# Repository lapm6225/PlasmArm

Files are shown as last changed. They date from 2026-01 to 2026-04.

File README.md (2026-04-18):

# PlasmArm

A 3-DOF (X, Y, Z) SCARA robotic arm controlled by an ESP32 with real-time WebSocket interface. Designed for compact plasma cutting applications in small workshops.

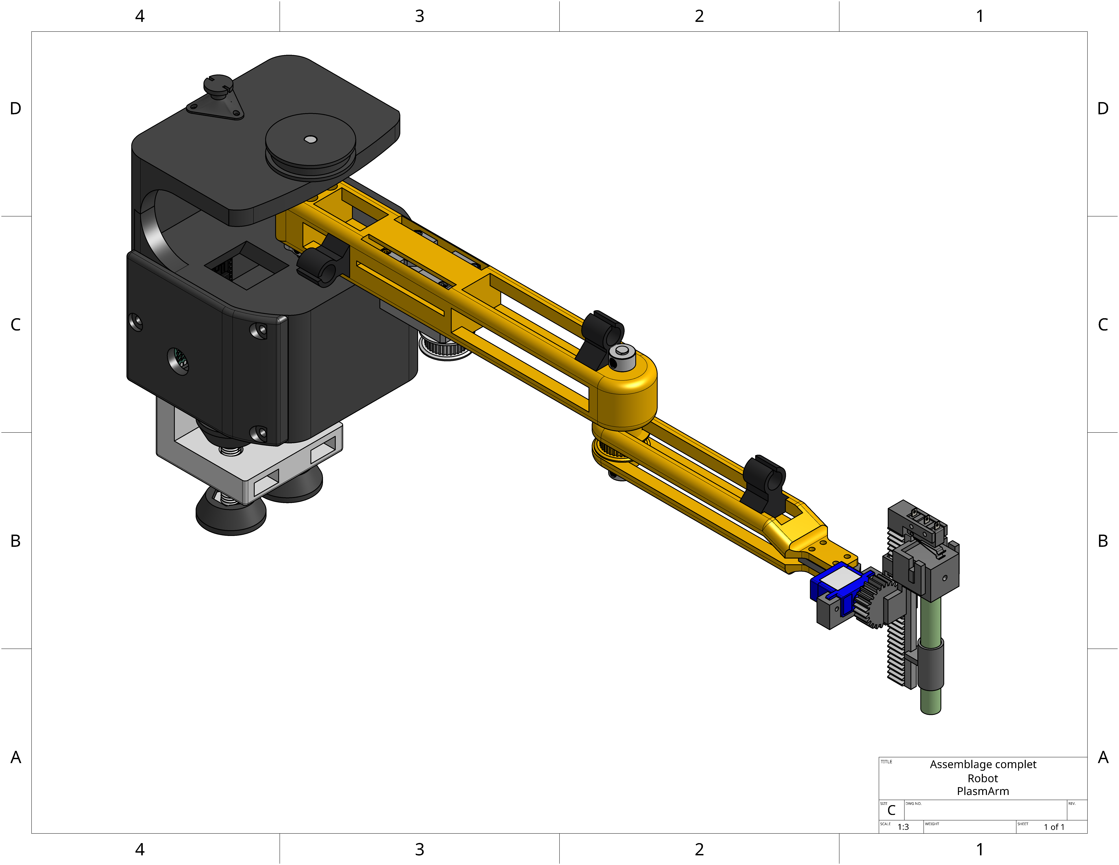
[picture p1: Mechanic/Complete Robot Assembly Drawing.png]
PlasmArm Robot


## Table of Contents

- [Overview](#overview)
- [Project Context](#project-context)
- [Electrical](#Electrical)
  - [Electrical Components](#Electrical-Components)
  - [Bill of Materials](#Bill-of-Materials)
  - [Wiring Diagram](#Wiring-Diagram)
- [Mechanical](#Mechanical)
  - [BoM & Drawings](#BoM-and-Drawings)
  - [Mechanical Project Files](#Mechanical-Project-Files)
  - [Assembly Instructions](#Assembly-Instructions)
- [Software](#Software)
  - [Software Installation](#software-installation)
    - [Prerequisites](#prerequisites)
    - [PlatformIO Setup](#platformio-setup)
    - [Python Client Setup](#python-client-setup)
  - [Configuration](#configuration)
  - [Building and Uploading](#building-and-uploading)
  - [Running the Robot](#running-the-robot)
  - [Architecture Overview](#architecture-overview)
    - [System Modules](#system-modules)
    - [FreeRTOS Task Structure](#freertos-task-structure)
    - [Kinematics](#kinematics)
    - [Trajectory Planning](#trajectory-planning)
  - [Web Interface](#web-interface)
  - [Testing](#testing)
  - [Licenses](#licenses)
  - [Troubleshooting](#troubleshooting)
  - [Project Structure](#project-structure)

---

## Overview

PlasmArm is a proof-of-concept for a compact, table-mounted SCARA robot designed for plasma cutting in small workshops. The robot folds when inactive to save floor space.

### Key Features

- **3-DOF Architecture**: X, Y positioning (2 joints) + Z axis (tool actuation)
- **ESP32** microcontroller with FreeRTOS for real-time dual-core task scheduling
- **Dynamixel XM430** servomotors for shoulder and elbow joints
- **SG90 servo** with rack-and-pinion mechanism for Z-axis
- **Limit switch** for tool contact detection
- **WebSocket** interface for real-time control via web browser
- **DXF import** support for vector drawings
- **PyQt6** graphical user interface

### Current Status

This is a **proof-of-concept** version at reduced scale where the plasma torch and metal sheet are replaced by a pencil and paper for safe testing and validation.

---

## Project Context

### Motivation

PlasmArm emerged from the need for space-saving solutions in small machining workshops. Traditional CNC plasma tables require significant floor space. This project proposes a compact alternative - a table-mounted SCARA robot that folds when inactive to free up workspace.

### Development Method

Agile methodology with incremental feature delivery throughout the project.

---

## Electrical

### Electrical Components

- **ESP32** (esp32doit-devkit-v1 or compatible)
- USB cable for programming

### Motors & Actuators

| Motor | Model | Function |
|---|---|---|
| Shoulder | Dynamixel XM430-W350 | Base joint (X-Y positioning) |
| Elbow | Dynamixel XM430-W350 | Second joint (X-Y positioning) |
| Z-Axis | SG90 (TowerPro) | Tool up/down actuation |
| End Effector | - | Pencil/pen holder (proof of concept) |

### Power Supply

- **12V DC** power supply (90W, 7.5A)
- 12V to 5V buck converter for ESP32 and SG90

### Electronics

- Level shifter (5V to 3.3V)
- Custom PCB (fit in the base)
- Limit switch (normally open) for Z-axis contact detection
- 10kΩ pull-up resistor for limit switch
- Diode (1N4148 or similar) for half-duplex UART

---

### Bill of Materials

| Component | Quantity | Notes |
|---|---|---|
| ESP32 Dev Kit | 1 | esp32doit-devkit-v1 |
| Dynamixel XM430-W350 | 2 | Shoulder and elbow joints |
| SG90 Servo | 1 | Z-axis actuation |
| 12V Power Supply | 1 | 90W, 7.5A |
| Buck Converter | 1 | 12V to 5V |
| Level Shifter | 1 | 5V to 3.3V |
| Limit Switch (NO) | 1 | Z-axis contact detection |
| 10kΩ Resistor | 1 | Pull-up for limit switch |
| 1N4148 Diode | 1 | Half-duplex UART |
| Electrolytic Capacitor | 1 | 10uF |
| Ceramic Capacitor | 3 | 10nF |

### ESP32 Pin Connections

| Function | GPIO Pin | Notes |
|---|---|---|
| Dynamixel RX | 16 | Serial2 RX |
| Dynamixel TX | 17 | Serial2 TX (with diode for half-duplex) |
| SG90 Servo (Z-axis) | 26 | PWM output |
| Limit Switch | 32 | Input with 10kΩ pull-up |
| 5V Power | - | From buck converter |
| 3.3V Reference | - | From Level Shifter |

### Wiring Diagram

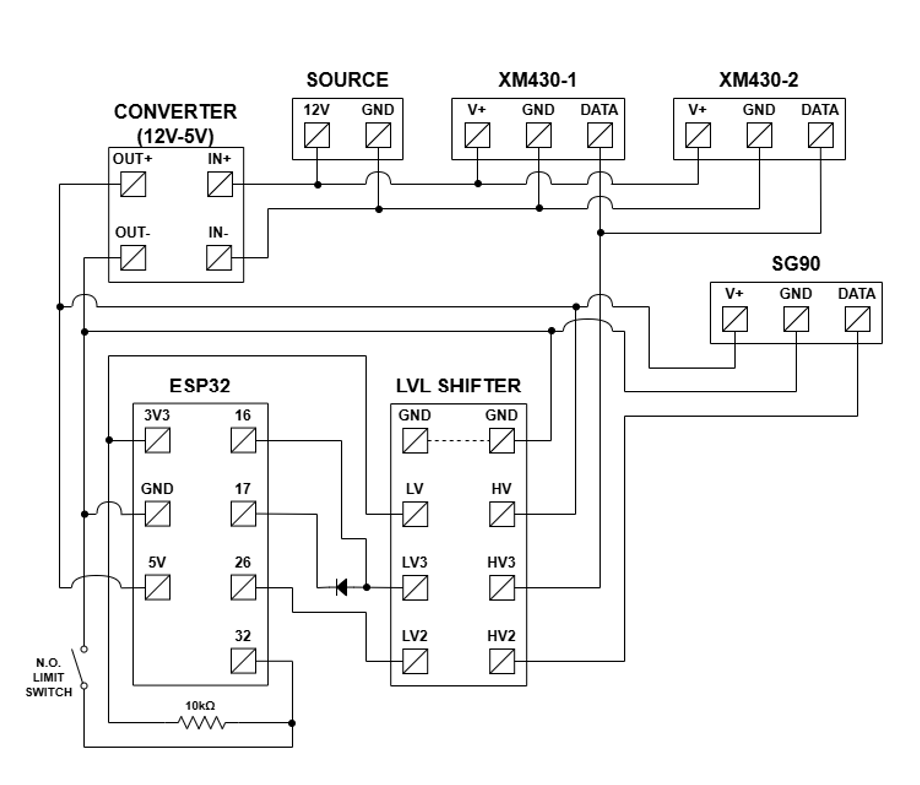
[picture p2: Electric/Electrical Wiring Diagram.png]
Wiring


---

### Connection Details

1. **Dynamixel Motors**: Daisy-chained, communicate via UART through level shifter to ESP32 pins 16 (RX) and 17 (TX)
2. **SG90**: PWM signal from GPIO 26 through level shifter
3. **Limit Switch**: GPIO 32 with 10kΩ pull-up to 3.3V
4. **Half-Duplex**: Diode on GPIO 17 prevents TX from blocking Dynamixel responses

---

### Mechanical 

### BoM and Drawings
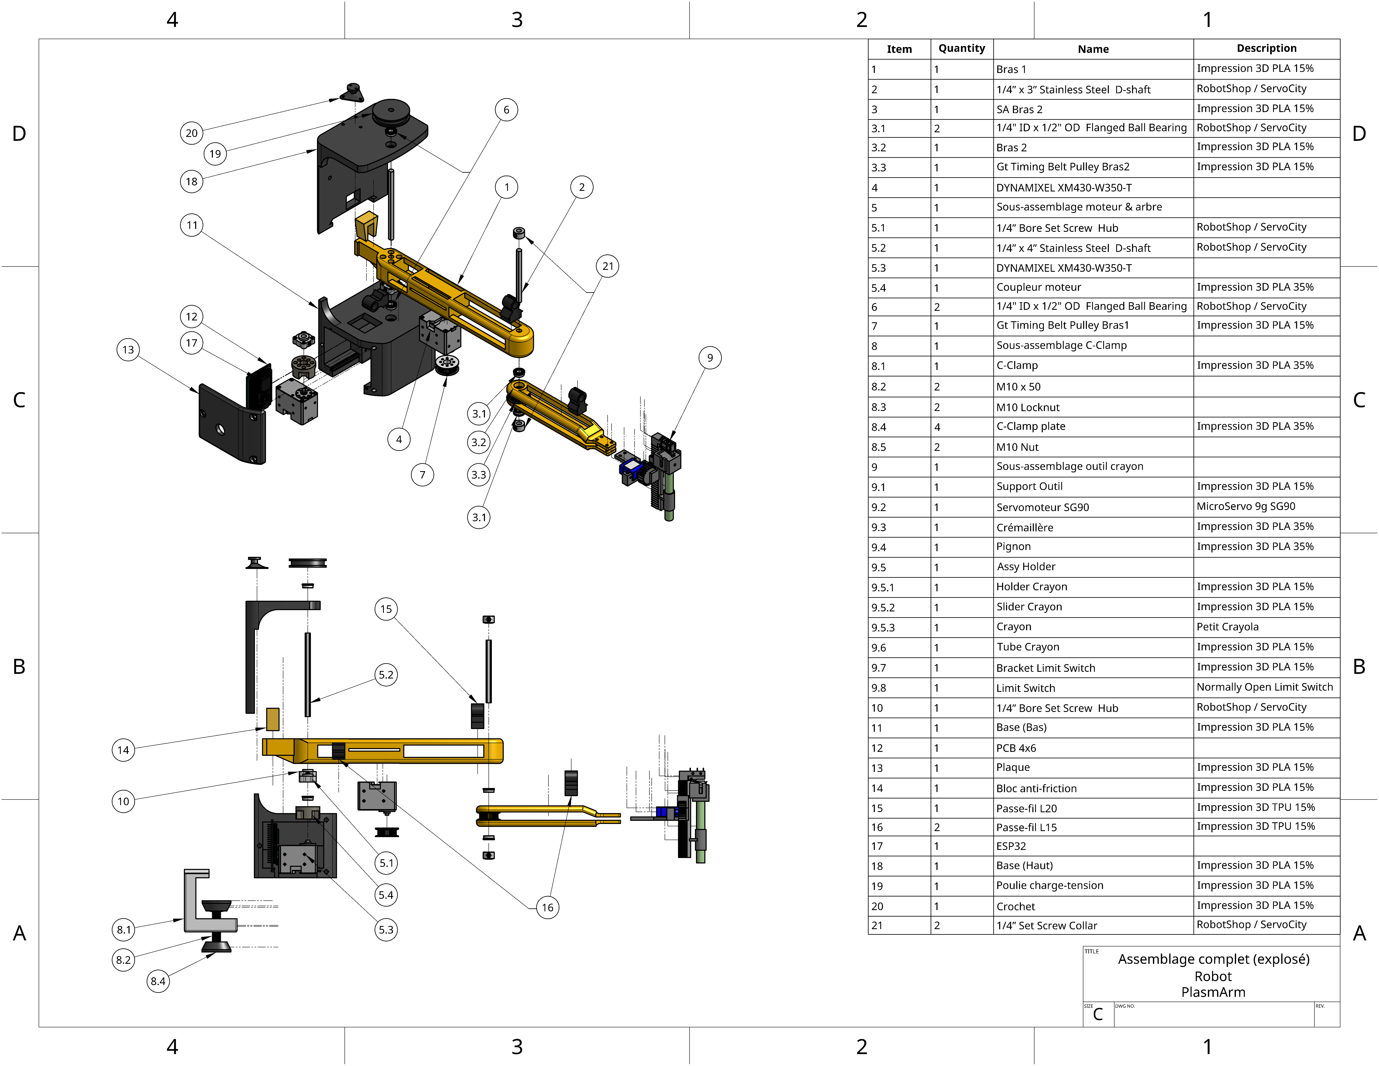
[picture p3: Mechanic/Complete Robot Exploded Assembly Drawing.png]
PlasmArm Robot Exploded

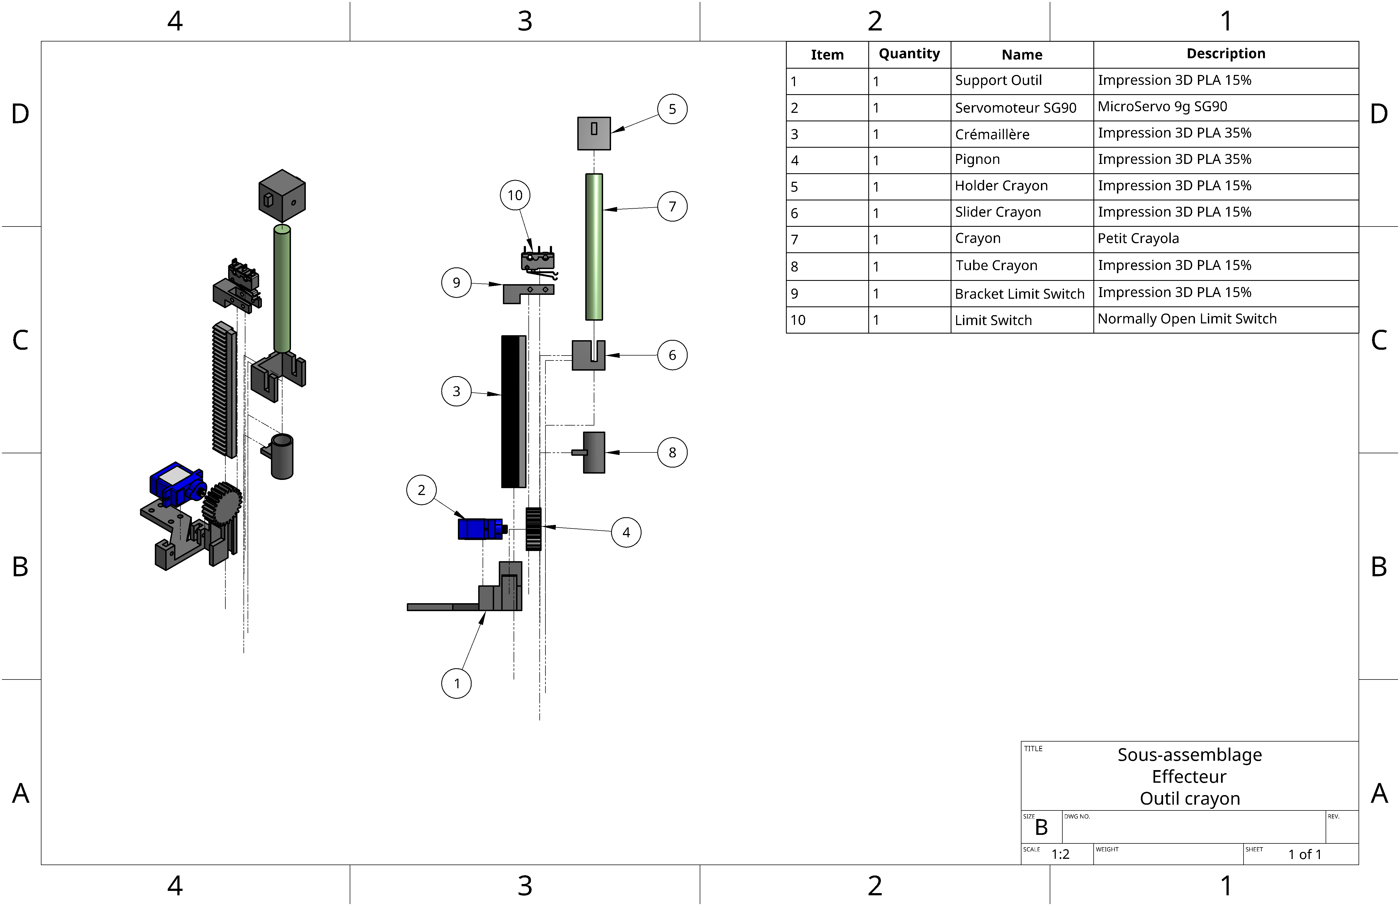
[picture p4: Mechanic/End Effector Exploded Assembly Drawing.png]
End Effector Exploded


### Mechanical Project Files
- [STL Printing Files](Mechanic/STL%20Printing%20Files)
- [STEP Part Files](Mechanic/STEP%20Part%20Files)

### Assembly Instructions
- [Assembly Instructions](Mechanic/Assembly%20Instructions.md)

---
## Software

### Software Installation

### Prerequisites

#### Windows

1. **Python 3.8+** - Download from https://www.python.org/
2. **Git** - Download from https://git-scm.com/
3. **PlatformIO** - Install via pip:
   ```bash
   pip install platformio
   ```

#### Linux/macOS

```bash
# Install Python if not present
brew install python3  # macOS
sudo apt install python3 python3-pip  # Linux

# Install PlatformIO
pip3 install platformio
```

### PlatformIO Setup

1. Navigate to the ESP32 directory:
   ```bash
   cd PlasmArm/ESP32
   ```

2. Install dependencies:
   ```bash
   pio pkg install
   ```

### Python Client Setup

The Python client provides a GUI for importing DXF files and sending commands to the robot.

1. Navigate to the Python directory:
   ```bash
   cd PlasmArm/Python
   ```

2. Create a virtual environment (recommended):
   ```bash
   python -m venv venv
   ```

3. Activate the virtual environment:
   - Windows: `venv\Scripts\activate`
   - Linux/macOS: `source venv/bin/activate`

4. Install dependencies:
   ```bash
   pip install -r requirements.txt
   ```
   
   Required packages:
   - PyQt6 (GUI)
   - websocket-client
   - ezdxf (DXF parsing)

---

## Configuration

### WiFi Configuration

Edit `ESP32/src/Config.h`:

```cpp
// Access Point Mode (create your own network)
#define WIFI_AP_MODE true
#define WIFI_AP_SSID "PlasmArm_ESP32"
#define WIFI_AP_PASSWORD "12345678"

// OR Station Mode (connect to existing WiFi)
#define WIFI_AP_MODE false
#define WIFI_STA_SSID "Your_Network_Name"
#define WIFI_STA_PASSWORD "Your_Password"
```

### Robot Physical Parameters

```cpp
// Arm lengths in millimeters
#define ARM_LENGTH_1 220.05f  // First link (base to elbow)
#define ARM_LENGTH_2 217.65f  // Second link (elbow to end effector)

// Joint angle limits (degrees)
#define THETA1_MIN 0.0f
#define THETA1_MAX 180.0f
#define THETA2_MIN -150.0f
#define THETA2_MAX 150.0f
```

### Motor IDs (Dynamixel)

Default IDs (verify with Dynamixel Wizard):
- Shoulder: ID 1
- Elbow: ID 2

---

## Building and Uploading

### Build the Project

```bash
cd PlasmArm/ESP32
pio run
```

### Upload to ESP32

```bash
pio run -t upload
```

### Open Serial Monitor

```bash
pio device monitor
```

Serial monitor is at **115200 baud**.

---

## Running the Robot

### 1. Power On

Connect the 12V power supply and USB cable to the ESP32.

### 2. Connect to WiFi

If using AP mode:
- Connect to network `PlasmArm_ESP32`
- Password: `12345678`

If using Station mode:
- Robot will connect to your specified WiFi network
- Check serial monitor for IP address

### 3. Send Commands

Use the Python GUI to:
- Move the arm to specific coordinates (jog control)
- Import and draw DXF files
- Control the tool/end effector (pen up/down)

---

## Architecture Overview

### System Modules

The system is divided into three interconnected modules: a PC user interface, an ESP32 embedded control unit and the SCARA arm mechanical unit.

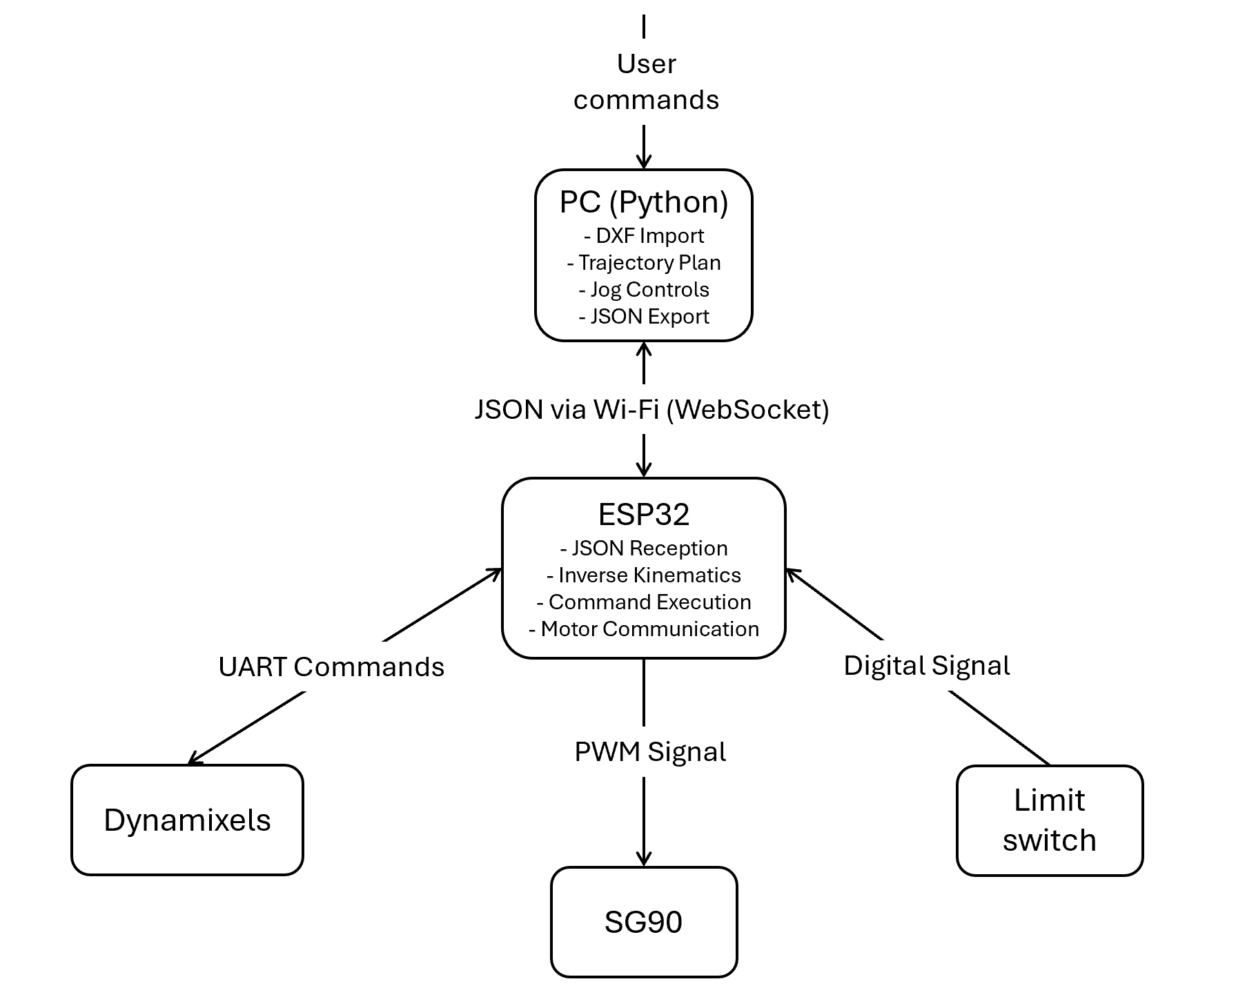
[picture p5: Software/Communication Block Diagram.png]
Communication Block Diagram


#### Module 1: User Interface (PC)

- **Technology**: Python with PyQt6
- **Functions**:
  - Import and parse DXF vector drawings
  - Generate trajectories centered on robot workspace
  - Manual jog controls
  - Export commands as JSON via Wi-Fi

#### Module 2: Embedded Control (ESP32)

- **Technology**: C++ with FreeRTOS
- **Functions**:
  - Receive JSON commands via WebSocket/Wi-Fi
  - Execute inverse kinematics calculations
  - Convert Cartesian coordinates to joint angles
  - High-frequency UART communication with Dynamixel motors

#### Module 3: SCARA Arm (Mechanical)

- **Technology**: 3D printed + Dynamixel servos
- **Components**:
  - Dynamixel XM430-W350 (Shoulder) - Time-Based Profile interpolation
  - Dynamixel XM430-W350 (Elbow) - Time-Based Profile interpolation
  - SG90 with rack-and-pinion for Z-axis
  - Limit switch for tool contact detection

### FreeRTOS Task Structure

The system uses two CPU cores:

```
Core 0: WebHandler (prio 1) + Trajectory Planner (prio 2)
Core 1: Motion Control (prio 3, 100 Hz loop)
```

| Task | Core | Priority | Function |
|---|---|---|---|
| WebHandler | 0 | 1 | Handle WebSocket commands from PC |
| Planner | 0 | 2 | Generate trajectory points from JSON |
| MotionControl | 1 | 3 | Execute motion at 100 Hz |

### Communication Flow

```
Web Client <--WebSocket--> WebHandler <--Command Queue--> Planner
                                                       |
                                                       v
                                            Trajectory Points
                                                       |
                                                       v
                                              Motion Queue
                                                       |
                                                       v
                                              MotionControl --> Motors
```

### Kinematics

The robot uses SCARA inverse kinematics:

#### Forward Kinematics
Convert joint angles (θ1, θ2) to Cartesian (x, y):
```
x = L1*cos(θ1) + L2*cos(θ1+θ2)
y = L1*sin(θ1) + L2*sin(θ1+θ2)
```

#### Inverse Kinematics
Convert Cartesian (x, y) to joint angles (θ1, θ2):
```
Using law of cosines and atan2
```

### Trajectory Planning

1. Receive target position and tool state from JSON
2. Generate linear path with waypoints
3. Apply trapezoidal velocity profile for smooth motion
4. Interpolate at 100 Hz for execution

---

## PyQt Interface Walktrough
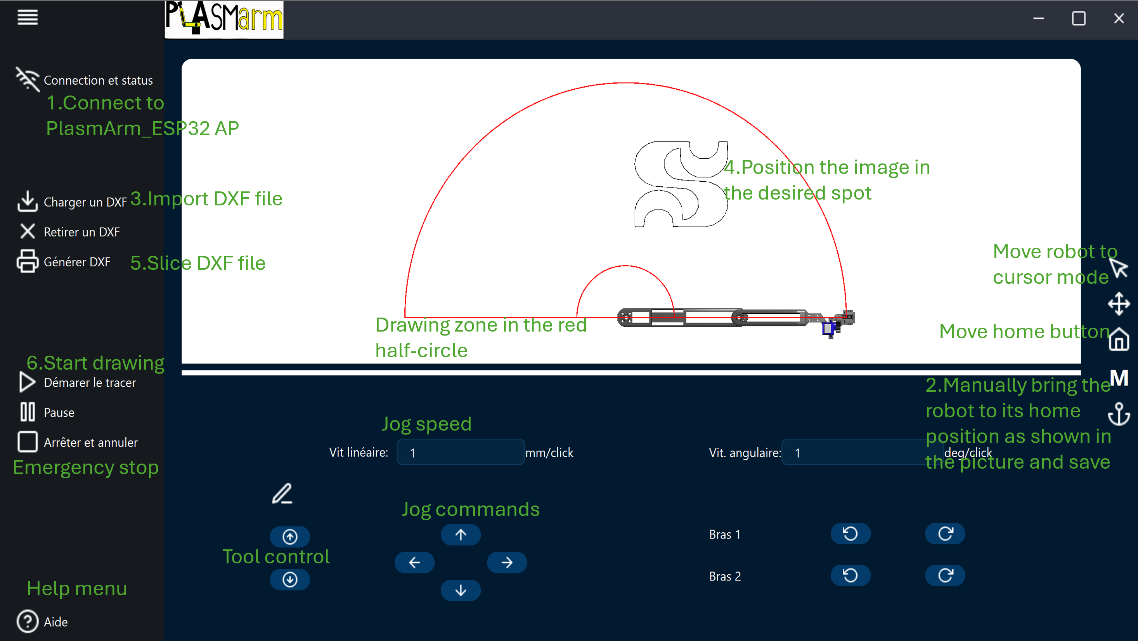
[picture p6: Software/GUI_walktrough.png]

The interface provides:

- **Manual Control**: Move arm to X, Y coordinates
- **DXF Upload**: Send drawing files to robot (via Python client)
- **Status Display**: Show current position and state
- **Tool Control**: Pen up/down commands

### WebSocket Commands

```json
// Move to position
{"type": "MOVE_TO", "x": 200, "y": 200, "speed": 100}

// Delay 
{"type": "DELAY", "ms": 500}

// Tool control
{"type": "TOOL", "state": "DOWN"}
{"type": "TOOL", "state": "UP"}

// Set home position
{"type": "SET_HOME"}
{"type": "SAVE_HOME"}
```

---

## Testing

The project includes built-in tests. Enable them in `ESP32/src/Config.h`:

```cpp
#define RUN_UNIT_TESTS true        // Automated kinematics/planner tests
#define RUN_VISUAL_TESTS true      // Detailed interpolation output
#define RUN_INTERACTIVE_TEST true  // Real hardware serial test
```

### Running Tests

1. Set test flags in `Config.h`
2. Build and upload: `pio run -t upload`
3. Open serial monitor at 115200 baud

See [ESP32/TEST_README.md](ESP32/TEST_README.md) for detailed testing instructions.

---

## Licenses

### Software

The Python code (DXF interpreter, GUI) and C++ firmware (ESP32) are distributed under the **GNU General Public License v3.0**.

This choice is primarily driven by the use of PyQt6, whose strong Copyleft license requires any project integrating it to adopt equivalent distribution conditions. GPLv3 ensures that future improvements by the community remain free and accessible to all.

### Hardware

3D printed models, CAD plans, and electrical schematics are distributed under the **CERN Open Hardware Licence - Weak (CERN-OHL-W)**.

---

## Troubleshooting

### Motors Not Moving

- Check power supply (12V, 3A minimum)
- Verify Dynamixel IDs are correct (default: 1 and 2)
- Check UART wiring (GPIO 16, 17)
- Use Dynamixel Wizard to verify motor communication

### Web Interface Not Loading

- Verify WiFi connection
- Check serial monitor for IP address

### Robot Not Reaching Target

- Check arm length parameters in Config.h
- Verify joint angle limits
- Ensure workspace boundaries are respected (half-circle, y > 0)

### Limit Switch Not Triggering

- Check wiring to GPIO 32
- Verify 10kΩ pull-up resistor is connected
- Test with multimeter

---

## Project Structure

```
PlasmArm/
├── ESP32/
│   ├── src/
│   │   ├── main.cpp           # Entry point, task creation
│   │   ├── Config.h           # All configuration constants
│   │   ├── core/
│   │   │   ├── Kinematics.cpp # Forward/Inverse kinematics
│   │   │   └── Planner.cpp    # Trajectory interpolation
│   │   ├── hardware/
│   │   │   ├── SG90.cpp       # Z-axis servo driver
│   │   │   └── Dynamixel2Arduino # Servo communication
│   │   ├── web/
│   │   │   └── WebServer.cpp  # WebSocket handler
│   │   └── test/              # Unit tests
│   ├── platformio.ini         # PlatformIO config
│   └── AGENTS.md              # Development notes
│
├── Python/
│   ├── main.py                # GUI application (PyQt6)
│   ├── communication.py       # WebSocket client
│   ├── animation.py          # Ui display
│   ├── dxf_display.py       # DXF file  management for ui
│   ├── dxf_parser.py         # DXF file parsing
│   ├── help_dialog.py       # Help window
│   └── requirements.txt      # Python dependencies
│
├── STL/                       # 3D print files (to be added)
│
├── Rapport final.pdf          # Technical report
│
├── LICENSE                    # GPLv3 (software)
│
├── CERN-OHL-W.txt            # Hardware license
│
└── README.md                  # This file
```

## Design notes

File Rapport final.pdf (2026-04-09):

i

UNIVERSITÉ DE SHERBROOKE
Faculté de génie
Département de génie robotique

## RAPPORT DE CONCEPTION FINAL – PLASMARM

Conception agile et ouverte en robotique GRO400

Présenté à
Catherine Véronneau
Raphaël Bisson

Présenté par
Équipe numéro 8
Arnaud Séguin – SEGA0300
Étienne Bérubé – BERE3507
Étienne Landry – LANE2209
Louis Lamontagne – LAML4835 Maxim Laplante – LAPM6225

Sherbrooke - 19 avril 2026

ii

## TABLE DES MATIÈRES

Liste des figures | iii
Liste des tableaux | iii
1. | Description de la réalisation technique du projet | 1
1.1 | Mise en contexte | 1
1.1.1 Objectifs, motivations et impacts visés par le projet | 1
1.1.2 Cahier des charges | 2
1.1.3 Mode de distribution sous licence ouverte, et justification du choix en fonction de l’impact
visé pour le projet | 4
1.2 | Description du système | 5
1.2.1 Architecture globale, modules, etc. | 5
1.2.2 Documentation technique mécanique | 6
1.2.3 Documentation technique informatique | 6
1.2.4 Documentation technique électrique | 6
1.3 | Performances du système et de l’intégration des modules, analysées en lien avec les
objectifs/cahier des charges à rencontrer | 8
1.3.1 Méthodes de validation et tests | 8
1.3.2 Résultats | 10
1.3.3 Recommandations pour la poursuite du projet | 10
1.4 | Bilan des livraisons | 10
2. | Références | 11
Annexe A | Exemple d’annexe | 12
Annexe B | Exemple d’annexe | 13

iii

## LISTE DES FIGURES

Figure 1 : Schéma-bloc de l’architecture globale du PlasmArm | 6
Figure 2 : Schéma électrique des composantes utilisées | 7

## LISTE DES TABLEAUX

Tableau 1 : Spécifications d'ingénierie (critères quantifiables) | 2
Tableau 2 : Fonctions (critères non quantifiables) | 3

1

## 1. DESCRIPTION DE LA RÉALISATION TECHNIQUE DU

## PROJET

### 1.1 MISE EN CONTEXTE

### 1.1.1 OBJECTIFS, MOTIVATIONS ET IMPACTS VISÉS PAR LE PROJET

L'idée du projet PlasmArm a émergé lors d’une discussion avec une connaissance possédant un

atelier d'usinage. Ces échanges ont mis en lumière le fait que les tables de découpe au plasma

CNC traditionnelles monopolisent une surface au sol énorme, ce qui s'avère problématique pour

les petits ateliers. Pour y remédier, le projet propose une alternative compacte : un robot

d'architecture SCARA, fixé au mur ou au sol, qui se replie sur lui-même lorsqu'il est inactif afin de

libérer l'espace de travail. Compte tenu des contraintes de temps, l'équipe réalise une preuve de

concept à échelle réduite où la torche et la tôle sont remplacées respectivement par un crayon et

du papier. Cette approche permet de tester et valider la cinématique, le contrôle et la précision

en toute sécurité, sans les risques et coûts liés au plasma.

Les objectifs de ce mandat sont à la fois matériels et logiciels. Tout d’abord, il s'agit de fabriquer

un bras rigide à trois axes, couvrant le plan XY avec deux joints et utilisant un actionneur pour

déplacer l'outil en Z. Le quatrième axe typique des SCARA, soit la rotation du poignet, a été

volontairement omise, la découpe au plasma étant omnidirectionnelle. Par la suite, sur le plan

informatique, l'objectif est de développer une interface utilisateur en Python et C/C++ intégrant

la cinématique inverse et capable d'interpréter un dessin de type DXF importé par l’utilisateur.

Encore, au niveau électrique, il est primordial de choisir des composantes pertinentes pour la

logique voulue et suffisamment fiables afin d’assurer la communication entre chacune d’entre

elles. Le développement est mené selon la méthode Agile afin de livrer des fonctionnalités de

manière incrémentale tout au long de la progression du projet.

Finalement, la principale motivation de cette démarche s'inscrit dans la philosophie du matériel

et du logiciel libres (Open Source). En diffusant publiquement les plans mécaniques, le code

source et la documentation sur un dépôt GitHub public, l'impact visé est double : optimiser

concrètement l'espace physique dans les petits ateliers industriels et offrir une solution de

2

fabrication automatisée abordable, accessible et reproductible pour l'ensemble de la

communauté maker.

### 1.1.2 CAHIER DES CHARGES

Cette section présente le cahier des charges final du projet PlasmArm, structuré afin de distinguer

les spécifications de performance mesurables des fonctions de conception non quantifiables. Le

tableau suivant regroupe les spécifications techniques pouvant être validées par des mesures

précises ou des données logicielles.

Tableau 1 : Spécifications d'ingénierie (critères quantifiables)

Spécification | Définition | Mesure | Niveau | Flexibilité
Vitesse linéaire | Vitesse de l'effecteur lors du tracé d'un segment. | Calcul logiciel | 0,1 m/s | Min.

Fréquence de
contrôle

Intervalle de rafraîchissement des commandes envoyées par l'ESP32 aux moteurs.

Chronomètre
interne (µs)
20 ms | Max.

Précision
positionnelle

Écart maximal entre la
trajectoire théorique du fichier DXF et le tracé physique.

Mesure
physique

± 1 mm Max.

Rayon de
travail

Distance maximale atteignable entre la base et l'extrémité de l'effecteur.

Mesure sur
CAO

300
mm

Min.

Masse de
l'effecteur

Masse totale de l'assemblage de l'effecteur (SG90, crémaillère, support et crayon).

Mesure sur
CAO
100 g | Max.

Alimentation
électrique

Tension électrique continue requise pour le fonctionnement des servomoteurs Dynamixel.

Multimètre 12 V (DC)

± 0.5 V

Capacité de
charge

Facteur de sécurité sur le couple pouvant être supporté par les servomoteurs Dynamixel.

Calcul
analytique
3 | Min.

Vibrations à
l’effecteur

Mouvements vibratoires dus au backlash des servomoteurs.

Mesure
physique
5 mm | Max.

3

Pour les fonctions dont la réussite dépend de choix architecturaux ou qualitatifs, le tableau

suivant détaille les solutions implémentées lors de l'intégration finale.

Tableau 2 : Fonctions (critères non quantifiables)

Fonctions | Notes à la conception | Respecté?
Être repliable dans l’espace de travail | Utilisation d'une architecture SCARA compacte et repliable permettant une fixation murale ou au sol pour libérer la surface de travail. | Oui

Être stable
mécaniquement

Intégration d'un appui de stabilisation pour assurer le contrebalancement du bras en porte-à-faux et d’un système de tension afin de réduire les vibrations à l’effecteur.

Oui

Piloter les actionneurs Pilotage direct des servomoteurs Dynamixel par l'ESP32 via une communication UART (half-duplex) afin d'éliminer la latence et le bruit observés sur les architectures multi-contrôleurs.

Oui

Détecter le plan de
découpe

Actionnement de la descente du crayon via un servomoteur SG90 et une crémaillère, dont l'arrêt est commandé par un interrupteur de fin de course (limit switch) dès le contact avec le plan.

Oui

Transmettre les
trajectoires

Transmission sans fil des trajectoires de découpe entre l'interface utilisateur PC et le robot par l'envoi de fichiers de commandes au format JSON via Wi-Fi.

Oui

Interpréter des fichiers
DXF

Interface logicielle développée en PyQt6 capable de traiter des fichiers DXF et de les centrer automatiquement par rapport à l'origine du robot.

Oui

Être distribué librement Publication exhaustive du projet sur un dépôt GitHub public, incluant les modèles CAO, le code source, le plan électrique et autres schémas pertinents. Oui

Être abordable | L'utilisation de composants standards et de l'impression 3D permet de respecter un budget réduit.
Oui
Être rigide | Choix d’un taux de remplissage du PLA des bras limitant la
mécaniquement | déformation verticale de l’effecteur due à la gravité et empêchant
l’abimement de l’insertion en D transmettant le mouvement.

Oui

Être compact | Passage des fils afin de limiter leur longueur, branchement des
structurellement | composantes sur un PCB caché et minimisation de la largeur des
pièces mécaniques.

Non

Être facilement | Assemblage et désassemblage simples à comprendre, nécessitant
démontable | peu d’effort physique et modulaires.

Oui

4

Dans le (Tableau 2), le seul critère non-quantifiable n’ayant pas été respecté est l’aspect structurel

compact du robot. Le CAO avait été conceptualisé pour intégrer le proto-board dans la base, mais

l’équipe a rencontré des difficultés au niveau du microcontrôleur ESP32 (pièce défectueuse), et

s’est résignée à utiliser un breadboard à l’extérieur de la base puisque l’équipe ne voulait pas tout

dé-souder et il ne restait pas assez de temps pour faire un PCB.

### 1.1.3 MODE DE DISTRIBUTION SOUS LICENCE OUVERTE, ET JUSTIFICATION DU

CHOIX EN FONCTION DE L’IMPACT VISÉ POUR LE PROJET

Le projet PlasmArm est distribué sous des licences ouvertes afin de permettre la communauté

maker de contribuer à cette technologie de découpe automatisée pour les petits ateliers

d'usinage. Le mode de distribution se divise en deux volets distincts : le logiciel et le matériel.

Pour le volet logiciel, le code source Python, incluant le module d'interprétation des fichiers DXF

et l'interface utilisateur, ainsi que le micrologiciel (firmware) en C++ exécuté par l'ESP32 sont

distribués sous la licence GNU GPLv3. Ce choix est d'abord dicté par l'utilisation de la bibliothèque

PyQt6, dont la licence Copyleft forte impose que tout projet l'intégrant adopte des conditions de

distribution équivalentes. La GPLv3 garantit que les futures améliorations apportées par la

communauté au logiciel de contrôle resteront libres et accessibles à tous.

Pour le volet matériel, les modèles d'impression 3D, les plans CAO et les schémas électriques sont

distribués sous la licence CERN-OHL-W (Open Hardware Licence - Weak). Cette licence est

spécifiquement conçue pour le matériel physique. La version « Weak » assure que toute

modification apportée directement à la conception mécanique du bras SCARA devra être partagée

publiquement. Simultanément, elle permet à un intégrateur d'utiliser ce bras robotique au sein

d'un système industriel plus vaste sans être contraint d'ouvrir les plans de son infrastructure

entière.

En conclusion, ces choix de licences maximisent l'impact visé en assurant que l'innovation au cœur

du PlasmArm demeure un bien commun, favorisant la collaboration technologique tout en

protégeant l'accessibilité de la solution.

5

### 1.2 DESCRIPTION DU SYSTÈME

1.2.1 ARCHITECTURE GLOBALE, MODULES, ETC.

L’architecture du système PlasmArm est conçue de manière modulaire afin d'assurer une

intégration fluide entre le logiciel de contrôle et la mécanique. Le système se divise en trois grands

modules interdépendants : l'interface utilisateur (PC), l'unité de contrôle embarquée (ESP32) et

le bras électromécanique (SCARA).

1. Module Interface Utilisateur et Planification (PC) Le flux d'opération débute sur un ordinateur

hôte via une interface graphique développée en Python (PyQt6). Ce module agit comme le

cerveau directeur. Il est responsable d'importer les dessins vectoriels (.DXF) et de les traduire en

une série de trajectoires centrées sur l'espace de travail du robot. L'interface offre également à

l'utilisateur des contrôles manuels (jog) et le démarrage de la séquence. Une fois la planification

terminée, les commandes de déplacement (coordonnées cartésiennes et états de l'outil) sont

encodées dans un fichier JSON et transmises sans fil à l'unité de contrôle via Wi-Fi.

2. Module de Contrôle Embarqué (ESP32) Ce module agit comme l'intermédiaire temps réel. Le

microcontrôleur ESP32 réceptionne les fichiers JSON et gère l'exécution séquentielle des

commandes. Il intègre le modèle mathématique de la cinématique inverse, traduisant les

coordonnées cartésiennes demandées en angles cibles pour chaque articulation du bras. L'ESP32

assure ensuite une communication directe (UART) et à haute fréquence avec les servomoteurs

pour garantir une fluidité de mouvement.

3. Module bras SCARA (Mécanique et Actionneurs) Le dernier maillon est l'exécution physique.

L'architecture SCARA à trois degrés de liberté utilise deux servomoteurs Dynamixel (Épaule et

Coude) pour le positionnement dans le plan XY. Ces moteurs intègrent leurs propres boucles de

contrôle internes (Time-Based Profile) pour assurer une interpolation lisse. L'axe Z, responsable

de l'actionnement de l'outil (crayon), est géré par un servomoteur SG90 entraînant une

crémaillère. Un interrupteur de fin de course (limit switch) vient clore la boucle de rétroaction

locale de cet axe en signalant à l'ESP32 le contact effectif de l'outil avec la surface de travail.

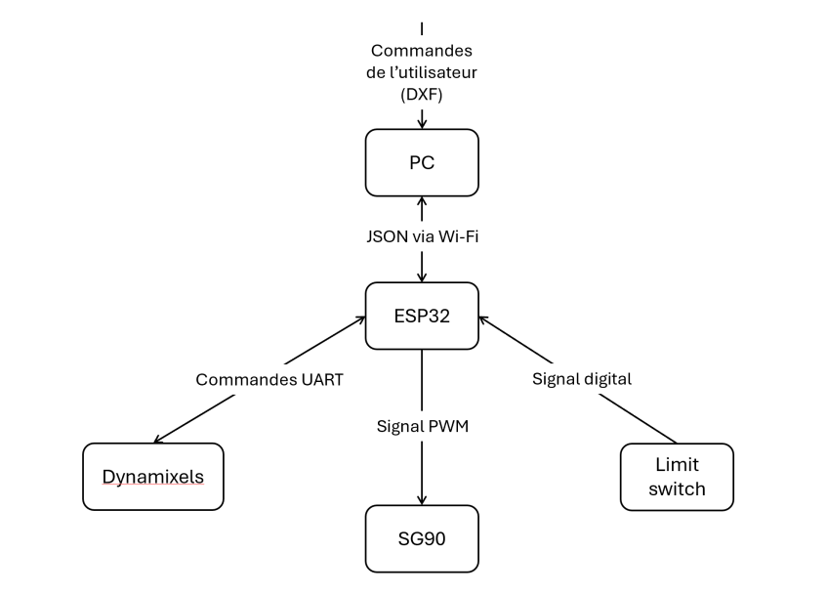
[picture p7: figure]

6

Figure 1 : Schéma-bloc de l’architecture globale du PlasmArm

### 1.2.2 DOCUMENTATION TECHNIQUE MÉCANIQUE

- Dessin d’assemblage explosé
- Liste des composantes importantes (donc ne pas mettre une liste exhaustive de toutes

les pièces de votre montage)

### 1.2.3 DOCUMENTATION TECHNIQUE INFORMATIQUE

- Plans et schémas
- Code

### 1.2.4 DOCUMENTATION TECHNIQUE ÉLECTRIQUE

Un schéma des branchements électriques est élaboré permettant une compréhension plus claire

des connexions et une reproduction plus simple.

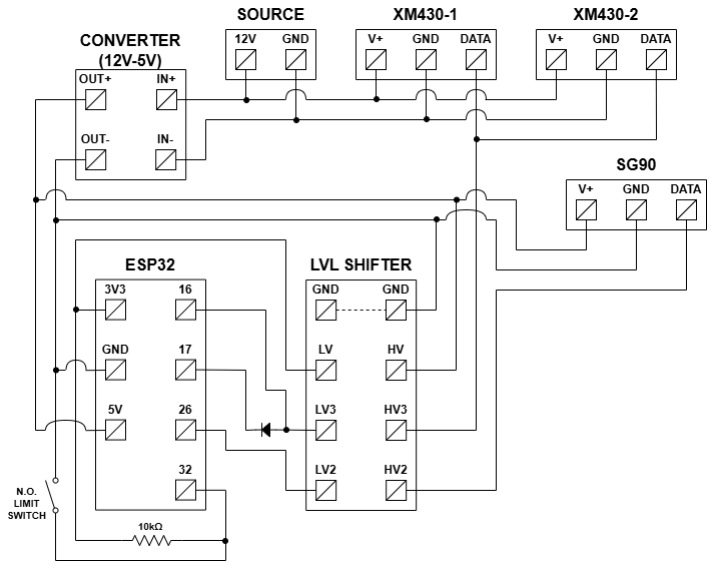
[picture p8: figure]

7

Figure 2 : Schéma électrique des composantes utilisées L’ensemble des composantes ci-dessus se trouvent sur le PCB rangé dans la base à l’exception des

actionneurs des joints et de l’interrupteur de fin de course. Ces derniers sont raccordés à la base

à l’aide de fils isolés dans une gaine. Les branchements sont résumés ainsi :

- Les deux servomoteurs Dynamixel (XM430) sont alimentés directement à la source de

12 V avant qu’elle soit convertie à 5 V, qui elle alimente le servomoteur de l’effecteur et

l’ESP32.

- Le level shifter permet de convertir les signaux de 5 à 3,3 V et sert donc aussi de référence

de 3,3 V pour l’ESP32.

- Les Dynamixel, branchés en daisy chain et passant par le level shifter, communiquent en

UART avec l’ESP32 aux broches 16 (RX) et 17 (TX) destinées à ce type de communication.

Afin d’assurer un canal Half-Duplex empêchant la transmission TX de monopoliser le fil

DATA et ainsi de laisser les Dynamixel répondre, une diode est ajoutée à la broche 17.

- Le fil DATA du SG90 de l’effecteur passe à travers le level shifter pour communiquer avec

la broche analogique 26 de l’ESP32.

- Une résistance de pull-up de 10 kΩ assure une lecture non-flottante à la broche 32 reliée

à l’interrupteur de fin de course normalement ouvert.

8

### 1.3 PERFORMANCES DU SYSTÈME ET DE L’INTÉGRATION DES MODULES, ANALYSÉES EN LIEN AVEC LES OBJECTIFS/CAHIER DES CHARGES À RENCONTRER

### 1.3.1 MÉTHODES DE VALIDATION ET TESTS

Dans le tableau suivant de validation des spécifications d’ingénierie, se référer au (Tableau 1) pour

consulter les détails spécifiques des critères quantifiables.

9

Tableau 3 : Validation des spécifications d’ingénierie (critères quantifiables)

Spécification | Justification | Validé?

Vitesse linéaire

Fréquence de

contrôle

Précision

positionnelle

Rayon de travail | Le rayon de travail du bras robot est de 440 mm, donc
| plus que 300 mm. Ceci a été vérifié directement sur le
| CAO.

Oui

Masse de l’effecteur | La masse de l’effecteur est de 45 ± 2g, ce qui est moins que
| la limite s’était fixée à 100g.

Oui

Alimentation

électrique

Capacité de charge

Vibrations à

l’effecteur

10

### 1.3.2 RÉSULTATS

### 1.3.3 RECOMMANDATIONS POUR LA POURSUITE DU PROJET

Pour la suite du projet, l’équipe recommande d’utiliser un PCB, plutôt qu’un proto-board. Les

soudures réalisées sur ce dernier ne sont pas propres et il est difficile de s’y retrouver s’il faut

déboguer le circuit. Un PCB permettrait de palier à ces problèmes et permettrait même de réduire

l’espace nécessaire à prévoir pour le circuit dans la base du robot. Une autre amélioration à

apporter au robot serait de remplacer les servomoteurs Dynamixel par des moteurs pas-à-pas.

Puisque la charge du bras est principalement appliquée sur les roulements à billes sur les axes de

rotation, les servomoteurs ne perçoivent pas un couple constant. Ceci fait en sorte que le backlash

causé par la boite de transmission est transmis jusqu’à l’effecteur du robot et cela induit des

vibrations importantes lors du tracé des formes. Un moteur pas-à-pas, puisqu’il contrôle la

position avec un champ magnétique, ne possède pas de backlash lié à une boîte de transmission

et permettrait un mouvement beaucoup plus fluide de l’effecteur. La solution présentement

employée par l’équipe est de mettre un élastique enroulé sur une poulie reliant le joint entre les

bras du robot à la base de celui-ci, mais cela est une solution temporaire qui sert à palier un défaut

des servomoteurs.

### 1.4 BILAN DES LIVRAISONS

Observations globales sur la réalisation des sprints, la répartition des tâches et l’atteinte des

objectifs des livraisons. Démontrez que vous avez bien contrôlé le déroulement et l’exécution du

projet (p.ex., burndown chart, heures travaillées par chacun, …).

11

## 2. RÉFÉRENCES

There are no sources in the current document.

12

## Annexe A EXEMPLE D’ANNEXE

13

## Annexe B EXEMPLE D’ANNEXE

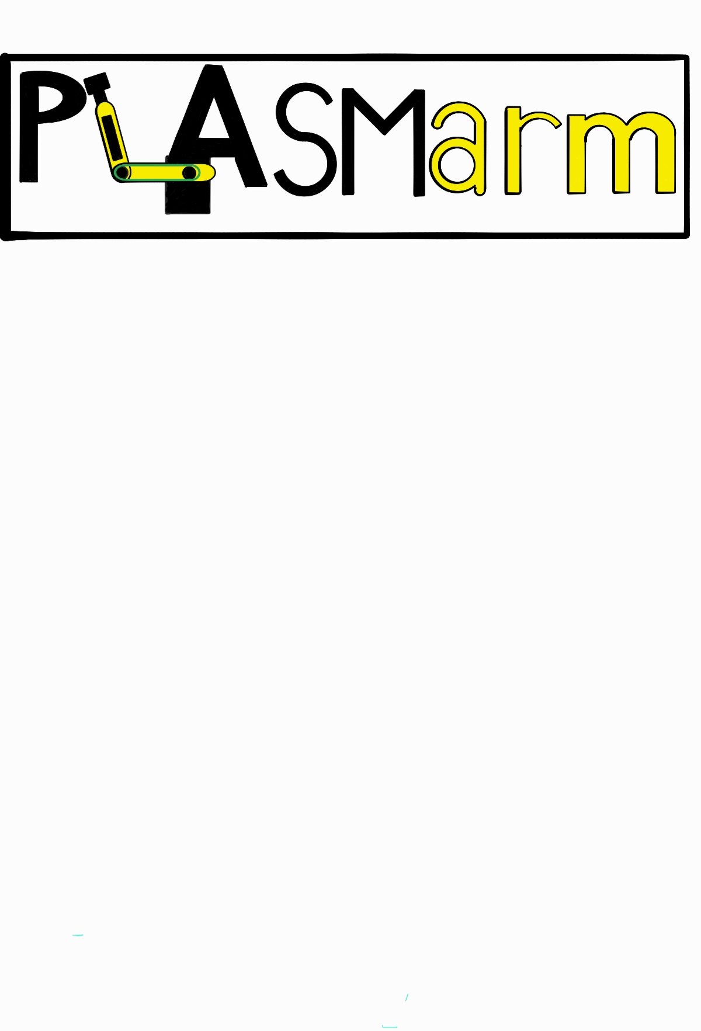
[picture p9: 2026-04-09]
Python/Plasmarm.png

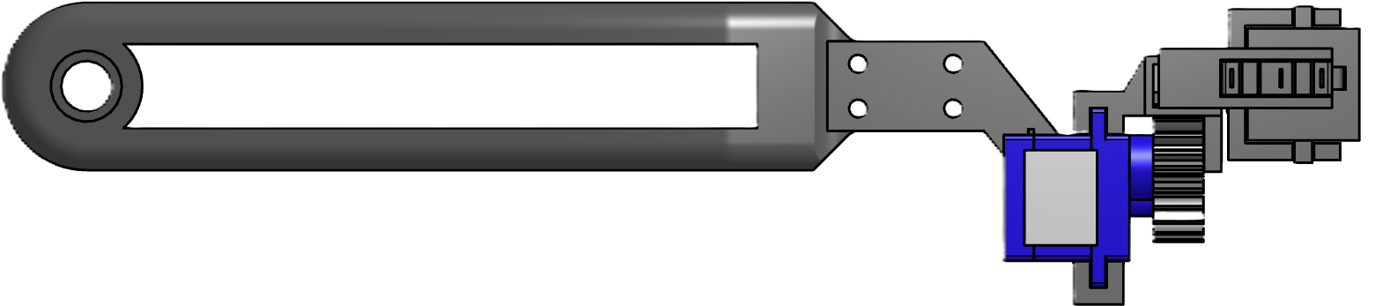
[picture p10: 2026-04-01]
Python/Bras2.png

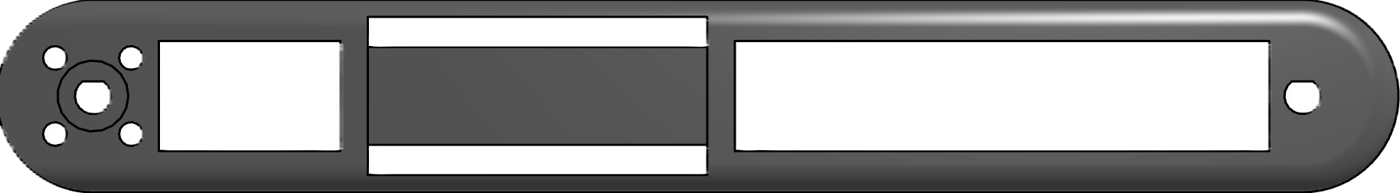
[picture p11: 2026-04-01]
Python/Bras1.png

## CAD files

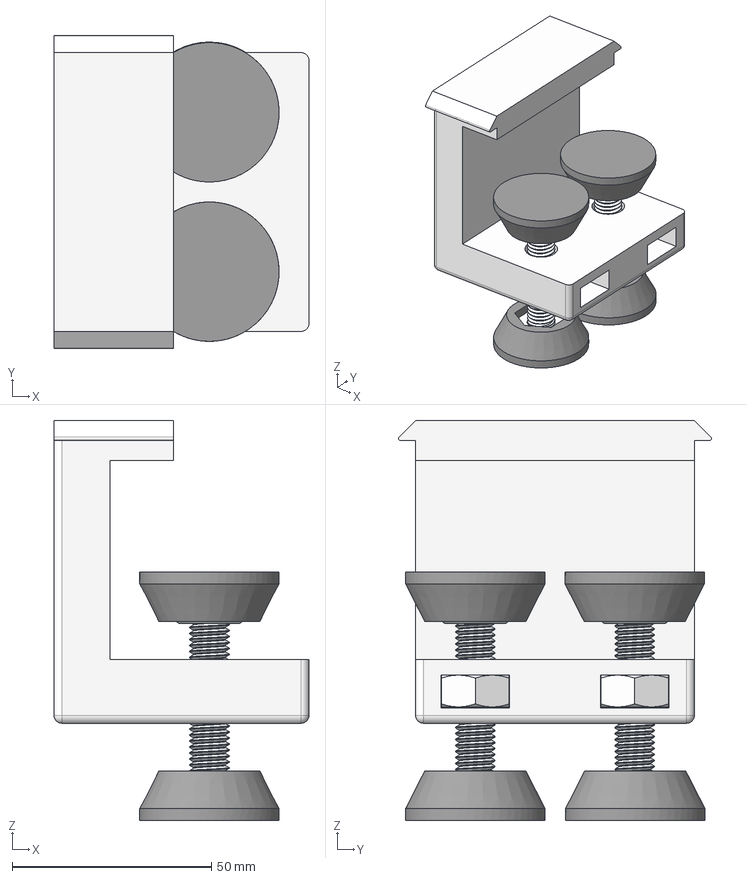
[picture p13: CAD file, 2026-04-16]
Mechanic/STEP Part Files/C-Clamp Assembly.step
64.0 x 78.6 x 100.4 mm
M10 Nut x 2
C-Clamp plate x 4
94645A220_High-Strength Steel Nylon-Insert Locknut x 4
M10 x 50 x 2
C-Clamp

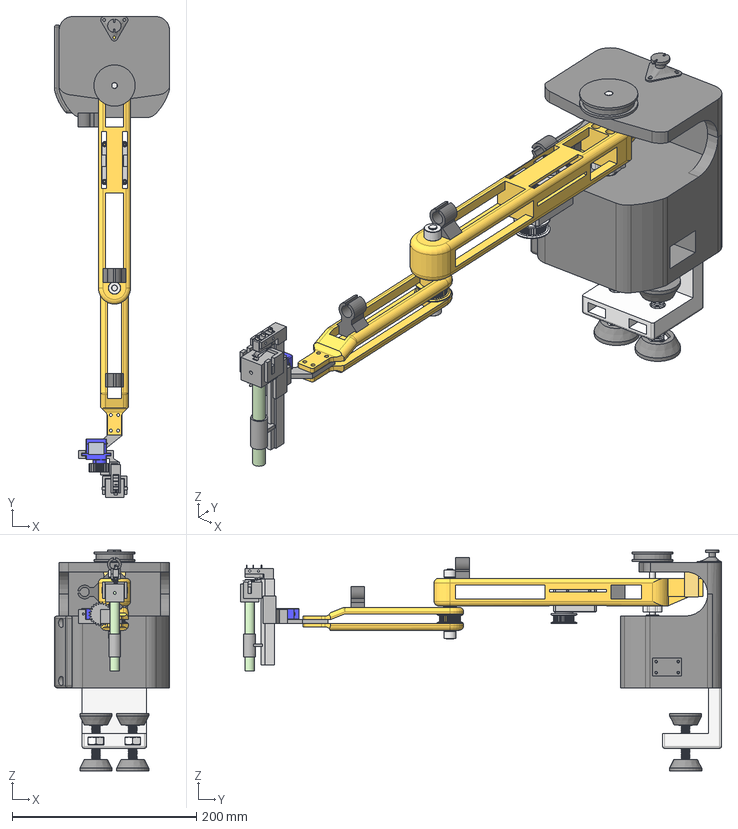
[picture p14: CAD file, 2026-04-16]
Mechanic/STEP Part Files/Whole Robot Assembly.step
125.0 x 522.7 x 239.7 mm
Bloc anti-friction
Crochet
Base (Haut)
Passe-fil L15 x 2
Base (Bas)
1/4� x 3� Stainless Steel D-sh aft
Plaque
Gt Timing Belt Pulley Bras1
Bras 1
Poulie charge-tension
Passe-fil L20
632138_91375A438 x 2
L�tpad Oval x 48
L�tpad rund x 560
PCB x 10
1/4� x 4� Stainless Steel D-sh aft
DC12_A01_SPACER_RING_1_3 x 2
WBH_M2_5X12_4 x 2
DC12_A01_SPACER_RING_1_2 x 2
DC12_A01_SPACER_RING_1_7 x 2
DC12_A01_SPACER_RING_1_5 x 2
WBH_M2_5X12_3 x 2
DC12_A01_SPACER_RING_1_1 x 2
DC12_A01_SPACER_RING_1_4 x 2
WBH_M2_5X12_2 x 2
DC12_A01_SPACER_RING_1 x 2
DC12_A01_SPACER_RING_1_6 x 2
WBH_M2_5X12_1 x 2
WBH_M2_5X12_7 x 2
WBH_M2_5X12 x 2
WBH_M2_5X12_6 x 2
DUMMY_DC12 x 2
WBH_M2_5X12_5 x 2
Coupleur moteur
2806-0005-0004_91390A117 x 2
Bras 2
Gt Timing Belt Pulley Bras2
SG90 Servo x 13
Bracket Limit Switch
Limit Switch
Tube Crayon
Cr�maill�re
Support Outil
Crayon
Slider Crayon
Holder Crayon
Pignon
M10 x 50 x 2
C-Clamp plate x 4
94645A220_High-Strength Steel Nylon-Insert Locknut x 4
C-Clamp
M10 Nut x 2

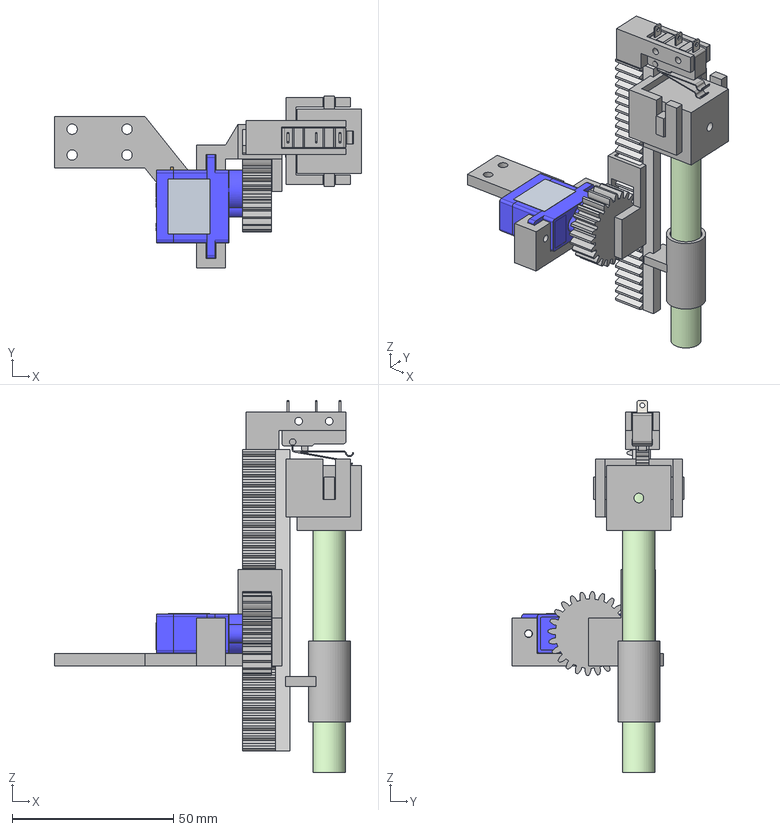
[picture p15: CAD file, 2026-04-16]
Mechanic/STEP Part Files/Effector Assembly.step
95.2 x 53.3 x 115.2 mm
Bracket Limit Switch
Support Outil
Limit Switch
Tube Crayon
Pignon
SG90 Servo x 13
Cr�maill�re
Crayon
Holder Crayon
Slider Crayon

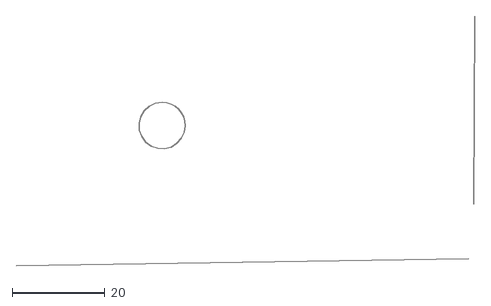
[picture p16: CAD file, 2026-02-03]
ESP32/src/test/python/dxf/drawing.dxf
98.7 x 53.7

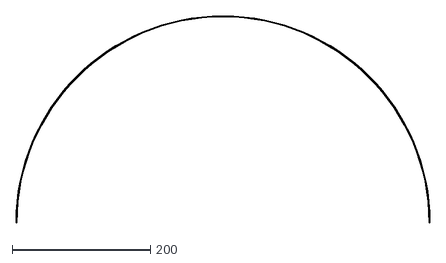
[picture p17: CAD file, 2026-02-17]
ESP32/src/test/python/integration/arc299ypos.dxf
598.0 x 299.0

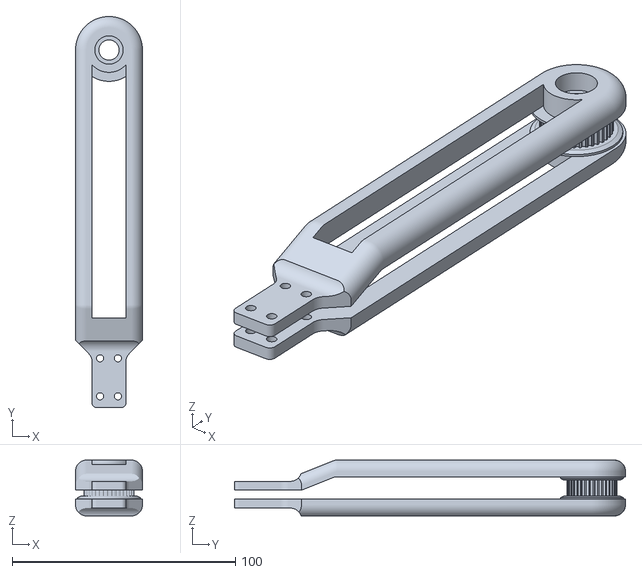
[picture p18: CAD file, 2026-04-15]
Mechanic/STL Printing Files/Bras 2 et Poulie.stl
30.0 x 175.0 x 25.0

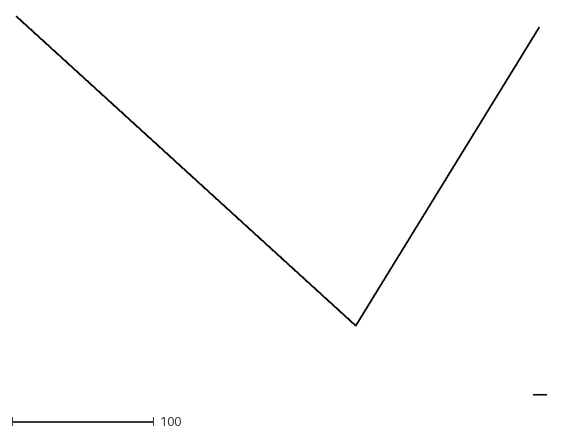
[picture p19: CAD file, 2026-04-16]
Python/export_robot.dxf
374.4 x 267.2

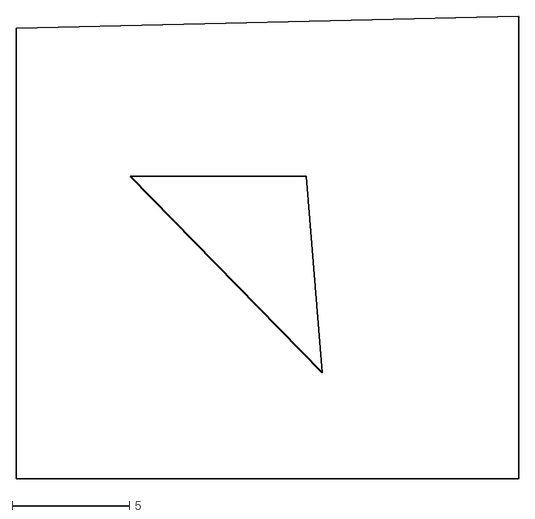
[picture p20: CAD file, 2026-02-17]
ESP32/src/test/python/integration/onshape_simple.dxf
21.5 x 19.8

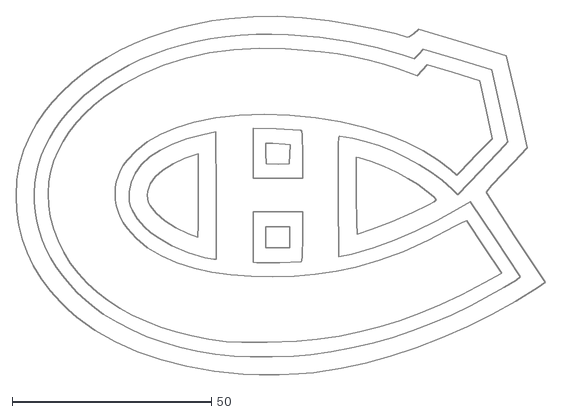
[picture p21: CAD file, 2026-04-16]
Python/canadiens_vide.dxf
132.8 x 90.0

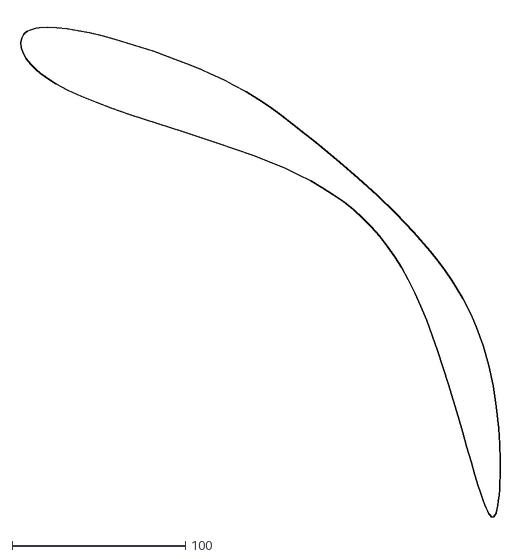
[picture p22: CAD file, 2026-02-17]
ESP32/src/test/python/integration/grosse_spline.dxf
280.1 x 289.5

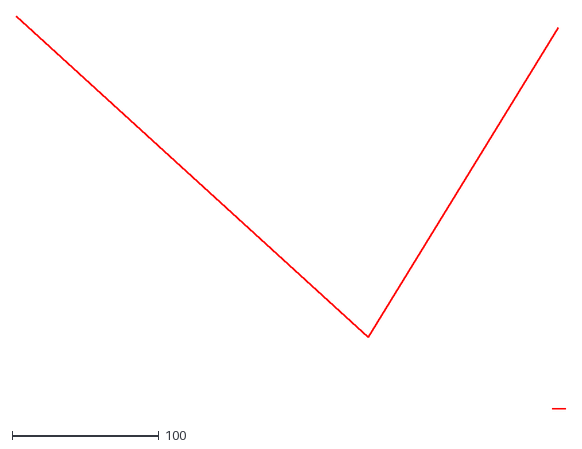
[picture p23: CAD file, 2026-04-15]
Python/rectangle.dxf
374.4 x 267.2

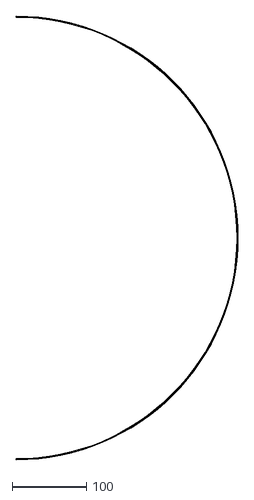
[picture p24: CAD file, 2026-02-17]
ESP32/src/test/python/integration/arc299.5.dxf
299.5 x 599.0

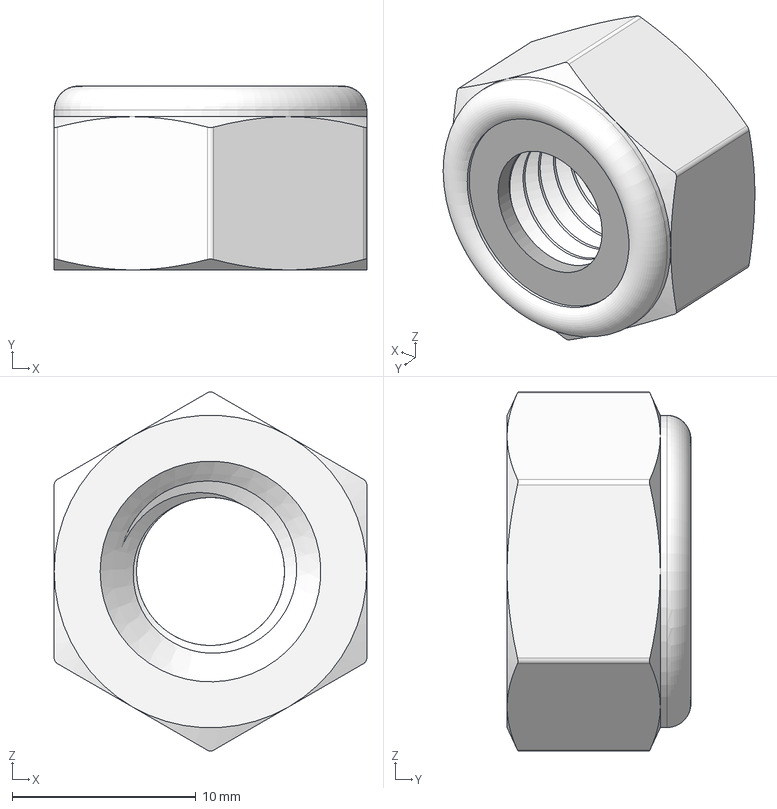
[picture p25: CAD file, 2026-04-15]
Mechanic/STEP Part Files/M10 Locknut.step
17.0 x 10.00 x 19.5 mm

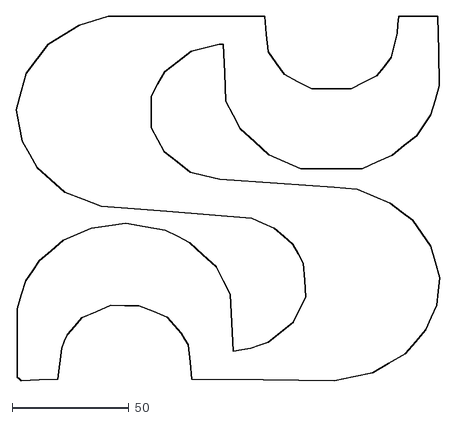
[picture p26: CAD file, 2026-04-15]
Python/udes.dxf
181.8 x 156.3

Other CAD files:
Mechanic/STEP Part Files/Tube Crayon.step
Python/BMW.dxf
Mechanic/STEP Part Files/DYNAMIXEL XM430-W350-T.step
Mechanic/STEP Part Files/Poulie charge-tension.step
Mechanic/STEP Part Files/1-4- ID x 1-2- OD Flanged Ball Bearing.step
Mechanic/STEP Part Files/1-4” Bore Set Screw Hub.step
Mechanic/STEP Part Files/1-4” x 2” Stainless Steel D-shaft.step
Mechanic/STEP Part Files/1-4” x 4” Stainless Steel D-shaft.step
Mechanic/STEP Part Files/Base (Bas).step
Mechanic/STEP Part Files/Base (Haut).step
Mechanic/STEP Part Files/Bloc anti-friction.step
Mechanic/STEP Part Files/Bracket Limit Switch.step
Mechanic/STEP Part Files/Bras 1.step
Mechanic/STEP Part Files/Bras 2 + Poulie.step
Mechanic/STEP Part Files/C-Clamp Plates.step
Mechanic/STEP Part Files/C-Clamp.step
Mechanic/STEP Part Files/Coupleur moteur.step
Mechanic/STEP Part Files/Crochet.step
Mechanic/STEP Part Files/Crémaillère.step
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

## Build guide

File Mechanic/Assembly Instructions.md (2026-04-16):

PlasmArm Robot
PlasmArm Robot

For the assembly instructions, refer to BoM and drawings above: 

**Sub-assembly 1: Motor 1, Coupling and Base**

1a) Unscrew central screw of the Dynamixel servo (5.3) output disk

1b) Mount this servo output disk to the custom coupling (5.4) using 4x (M2 X 10mm)

1c) Mount the custom coupling (5.3) to the bore set screw hub (5.1) using 4x (6-32 X 3/8")

1d) Mount this coupling sub-assembly back onto the Dynamixel servo (5.3) using the central screw of step 1a)

1e) Insert this servo and coupling into the robot base (11) and fix using 8x (M2.5 X 16mm)

1f) Insert bearing (6) into the planned hole on the base (1)

**Sub-assembly 2: Arm 1, Shafts and Motor 2**

2a) Insert 4" D-shaft (5.2) and 3" D-shaft (2) into D-shaped bores of robot arm (1) according to assembly drawing

2b) Mount bore set screw hub (10) onto 4" D-shaft and arm 1 using 4x (6-32 X 3/4")

2c) Glue friction bloc (14) and cable management attachements (15 and 16) onto arm 1 according to positions in assembly drawing

2d) Mount Gt timing belt pulley (7) onto Dynamixel servo (4) output disk using 4x (M2 X 10mm)

2e) Mount Dynamixel servo (4) onto arm 1 using 4x (M2.5 X 5mm) in the adjustment slots, tighten in later step when adjusting Gt timing belt tension

2f) Insert the 4" D-shaft (5.2) that is on this sub-assembly into the bearing (6) on base (1) and into the motor coupling. Fix the shaft to the motor coupling using the set screw on bore hub (5.1)

**Sub-assembly 3: Base top**

3a) Mount elastic tensioner (20) onto base top (18) using 3x (M4 X 12mm)

3b) Insert bearing (6) into the planned hole on the base top (18)

3c) Insert base top (18) into 4" D-shaft (5.2) and mount base top onto base (1) using 3x (M5 X 15mm)

3d) Insert elastic pulley (19) onto top of 4" D-shaft (5.2)

**Sub-assembly 4: Arm 2**

4a) Pass the timing belt through the second arm and wrap it around the 2 pulleys (3.3 & 7), then tighten the timing belt by adjusting and fixing the distance of the Dynamixel servomotor (4)

4b) Press fit the 2 bearings (21) on each side of the second arm (3.2)

4c) Connect the second arm under the first arm by passing the D-shaft (2) through both parts

4d) Lock the shaft (2) and the arms with two set screw collars (21) on each end of the shaft

4e) Glue the cable management attachment (16) to the second arm (3.2) as seen in the exploded view diagram

**Sub-assembly 5: End Effector**

5a) Insert the spur gear (4) on the rotating arm of the SG90 (2)

5b) Insert and fix the SG90 in the tool bracket (1) with 2x (M2.5 X 8mm) screws

5c) Press fit the crayon (7) in the crayon holder (5)

5d) Slide the crayon holder (5) in the slider (6)

5e) Pass the crayon through the tube (8)

5f) Glue the tube (8) and the slider (6) to the rack (3)

5g) Slide the rack assembly (3) in the tool bracket slot (1)

5h) Fix the limit switch (10) to the limit switch bracket (9) with 2x (M2 X 12mm) screws and nuts

5i) Glue the limit switch bracket (9) to the top of the rack (3) as shown in the exploded view

5j) Fix the tool bracket (1) to the end of the second arm with 4x (M2.5 X 15mm) screws

**Sub-assembly 6: Base Cover & C-clamp**

6a) Make all the necessary electrical connections and insert the PCB in the base (11), then screw the door (13) to the base with 3x (M3 X 15mm) screws

6b) Put the 2 M10 nuts (8.5) in the C-clamp slots (8.1)

6c) Insert the 2x (M10 X 50) bolts (8.2) halfway through the 2 M10 nuts (8.5)

6d) Screw the 2 M10 locknuts (8.3) at the free end of the 2 (M10 X 50) bolts (8.2)

6e) Press fit the 4 C-clamp plates (8.4) at each end of the bolts

6f) Press fit the assembled C-clamp (8) in the base's triangular slot

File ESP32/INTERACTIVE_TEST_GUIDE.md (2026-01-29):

# Guide du Test Interactif avec Moteurs Réels

Le test interactif vous permet d'entrer des coordonnées (x, y) via le Serial Monitor et de voir en temps réel :
- ✅ Tous les points d'interpolation
- ✅ Les angles calculés (θ1, θ2) pour chaque point
- ✅ Les moteurs qui bougent réellement
- ✅ La vérification de précision

## 🚀 Activation

### Étape 1 : Configurer les pins des moteurs

Les pins sont déjà configurés dans `Config.h` :
- **Motor 1** : STEP=19, DIR=18, ENABLE=27
- **Motor 2** : STEP=14, DIR=12, ENABLE=13

### Étape 2 : Activer le mode interactif

Ouvrez `src/Config.h` et changez :
```cpp
#define RUN_INTERACTIVE_TEST false
```
en :
```cpp
#define RUN_INTERACTIVE_TEST true
```

Assurez-vous que les autres modes de test sont à `false` :
```cpp
#define RUN_UNIT_TESTS false
#define RUN_VISUAL_TESTS false
```

### Étape 3 : Connecter les moteurs

Connectez vos stepper motors selon la configuration :
- Motor 1 (Base) : STEP=19, DIR=18, ENABLE=27
- Motor 2 (Elbow) : STEP=14, DIR=12, ENABLE=13

### Étape 4 : Compiler et téléverser

```bash
platformio run --target upload
```

### Étape 5 : Ouvrir le Serial Monitor

- Vitesse : **115200 baud**
- **Important** : Assurez-vous que "Both NL & CR" ou "Newline" est sélectionné dans le Serial Monitor

## 📝 Commandes Disponibles

### 1. Déplacer vers une position
```
200,150
```
ou
```
move 200,150
```
Déplace le robot vers la position (200mm, 150mm)

### 2. Retour à la position d'origine
```
home
```
Déplace le robot vers (0, 0)

### 3. Afficher la position actuelle
```
pos
```
ou
```
position
```
Affiche :
- Position actuelle (x, y)
- Angles actuels (θ1, θ2)
- Angles des moteurs
- État de mouvement

### 4. Séquence de test automatique
```
test
```
Exécute une séquence de 4 mouvements prédéfinis pour tester le système

### 5. Aide
```
help
```
Affiche la liste des commandes disponibles

## 📊 Exemple de Sortie

Quand vous entrez `200,150`, vous verrez :

```
═══════════════════════════════════════════════════════════
MOVING TO TARGET
═══════════════════════════════════════════════════════════
From: (150.00, 150.00) mm
To: (200.00, 150.00) mm

📊 Interpolation: 25 points generated

Point# | X (mm)  | Y (mm)  | θ1 (°)  | θ2 (°)  | Status
─────────────────────────────────────────────────────────────
    0 |  150.00 |  150.00 |   45.00 |   30.00 | ✅
    5 |  160.00 |  150.00 |   48.50 |   32.20 | ✅
   10 |  170.00 |  150.00 |   52.00 |   34.40 | ✅
   15 |  180.00 |  150.00 |   55.50 |   36.60 | ✅
   20 |  190.00 |  150.00 |   58.00 |   38.80 | ✅
   24 |  200.00 |  150.00 |   60.00 |   40.00 | ✅
─────────────────────────────────────────────────────────────
Summary: 25 passed ✅, 0 failed ❌

⏳ Waiting for motors to reach target...
✅ Motors reached target position

Final angles: θ1=60.00°, θ2=40.00°

✅ Movement command completed!
═══════════════════════════════════════════════════════════
```

## 🎯 Fonctionnalités

### Affichage en Temps Réel
- Chaque point interpolé est affiché avec ses coordonnées et angles
- Le statut ✅/❌ indique si la vérification round-trip a réussi
- Les moteurs bougent réellement pendant l'affichage

### Vérification Automatique
Pour chaque point interpolé :
1. Calcul de la cinématique inverse (position → angles)
2. Vérification round-trip (angles → position)
3. Calcul de l'erreur
4. Affichage du statut

### Gestion des Erreurs
- Si une position n'est pas atteignable, un message d'erreur clair est affiché
- Les limites de l'espace de travail sont affichées
- Timeout de 30 secondes pour éviter les blocages

## 🔧 Personnalisation

### Changer la vitesse d'interpolation

Dans `TestInteractive.cpp`, modifiez :
```cpp
Planner planner(DEFAULT_SPEED, ACCELERATION);
```
ou dans `Config.h` :
```cpp
#define DEFAULT_SPEED 50.0f  // mm/s
```

### Changer la position de départ

Dans `TestInteractive.cpp`, modifiez :
```cpp
Point2D currentPos(150.0f, 150.0f);  // Votre position de départ
```

### Afficher plus/moins de détails

Dans `TestInteractive.cpp`, dans la fonction `executeMove()`, modifiez :
```cpp
if (showDetails && (index % 5 == 0 || index == 0 || index == numPoints - 1)) {
    // Changez 5 en 1 pour tout afficher, ou 10 pour moins de détails
}
```

## ⚠️ Notes Importantes

1. **Les moteurs doivent être connectés** - Le test utilise les vrais moteurs
2. **Vitesse du Serial Monitor** - Doit être à 115200 baud
3. **Format des commandes** - Utilisez `x,y` ou `move x,y` (pas d'espaces autour de la virgule)
4. **Attente du mouvement** - Le système attend que les moteurs atteignent la position avant d'accepter la prochaine commande
5. **Timeout** - Si un mouvement prend plus de 30 secondes, un avertissement est affiché

## 🐛 Dépannage

### Les moteurs ne bougent pas
- Vérifiez les connexions (STEP, DIR, ENABLE)
- Vérifiez que les pins dans `Config.h` correspondent à votre câblage
- Vérifiez que les moteurs sont alimentés

### Erreur "Target not reachable"
- Vérifiez que les coordonnées sont dans l'espace de travail
- Espace de travail : distance de l'origine entre `minReach` et `maxReach`
- Pour un robot avec L1=150mm, L2=150mm : max reach = 300mm

### Le Serial Monitor ne répond pas
- Vérifiez la vitesse (115200 baud)
- Vérifiez que "Newline" est sélectionné
- Réinitialisez l'ESP32

### Les angles semblent incorrects
- Vérifiez les longueurs de bras dans `Config.h` (ARM_LENGTH_1, ARM_LENGTH_2)
- Vérifiez que les moteurs sont correctement montés (sens de rotation)

## 📈 Exemple de Session Complète

```
╔══════════════════════════════════════════════════════════╗
║      INTERACTIVE INTEGRATION TEST                       ║
║      With Real Stepper Motors                           ║
╚══════════════════════════════════════════════════════════╝

Motors initialized and enabled
Arm lengths: L1=150.0 mm, L2=150.0 mm
Max reach: 300.0 mm

Initial position set
Current position: (150.00, 150.00) mm
Current angles: θ1=45.00°, θ2=30.00°

Commands:
  x,y          - Move to position (e.g., '200,150')
  move x,y     - Same as above
  home         - Move to home position (0,0)
  pos          - Show current position and angles
  test         - Run test sequence
  help         - Show this help

═══════════════════════════════════════════════════════════
Ready for commands. Enter coordinates or 'help' for commands.
═══════════════════════════════════════════════════════════

> 200,150
═══════════════════════════════════════════════════════════
MOVING TO TARGET
═══════════════════════════════════════════════════════════
From: (150.00, 150.00) mm
To: (200.00, 150.00) mm

📊 Interpolation: 25 points generated
...
✅ Movement command completed!

> pos
Current position: (200.00, 150.00) mm
Current angles: θ1=60.00°, θ2=40.00°
Motor 1 angle: 60.00°
Motor 2 angle: 40.00°
Motor 1 moving: NO
Motor 2 moving: NO

> home
...
✅ Movement command completed!
```

## 🎓 Comprendre les Résultats

- **Point#** : Numéro du point dans la séquence d'interpolation
- **X, Y** : Coordonnées cartésiennes en millimètres
- **θ1, θ2** : Angles des joints en degrés
- **Status** : ✅ = vérification round-trip réussie, ❌ = échec

Le système vérifie automatiquement que chaque point peut être atteint avec les angles calculés !

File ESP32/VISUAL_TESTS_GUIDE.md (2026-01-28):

# Guide des Tests Visuels

Les tests visuels affichent des informations détaillées pour comprendre et vérifier le fonctionnement du système d'interpolation et de cinématique.

## 🎯 Tests Visuels Disponibles

### Test 1: Interpolation Visualization
Affiche tous les points d'interpolation générés entre deux positions.

**Ce que vous verrez :**
- Point de départ et d'arrivée
- Distance totale
- Tous les points interpolés avec leur numéro
- Distance depuis le départ et pourcentage de progression

### Test 2: Angle → Position (Forward Kinematics)
Vérifie que les angles calculent correctement les positions.

**Ce que vous verrez :**
- Différentes combinaisons d'angles (θ1, θ2)
- Position résultante pour chaque combinaison
- Distance depuis l'origine
- Vérification si la position est dans l'espace de travail

### Test 3: Position → Angles (Inverse Kinematics)
Vérifie que les positions calculent correctement les angles.

**Ce que vous verrez :**
- Différentes positions cibles (x, y)
- Angles calculés (θ1, θ2)
- Vérification aller-retour (round-trip)
- Erreur de précision (Δx, Δy, distance)

### Test 4: Full Path Visualization ⭐ **LE PLUS IMPORTANT**
Test complet qui combine interpolation + cinématique.

**Ce que vous verrez :**
- Tableau avec tous les points interpolés
- Pour chaque point :
  - Coordonnées (x, y)
  - Angles calculés (θ1, θ2)
  - Erreur de vérification
  - Statut ✅ ou ❌
- Résumé final avec nombre de points passés/échoués

## 🚀 Comment Activer les Tests Visuels

### Méthode 1 : Via Config.h (Recommandé)

1. Ouvrez `src/Config.h`
2. Trouvez la section "Test Mode Configuration"
3. Changez :
   ```cpp
   #define RUN_VISUAL_TESTS false
   ```
   en :
   ```cpp
   #define RUN_VISUAL_TESTS true
   ```
4. Assurez-vous que `RUN_UNIT_TESTS` est à `false`
5. Compilez et téléversez :
   ```bash
   platformio run --target upload
   ```
6. Ouvrez le Serial Monitor (115200 baud)

### Méthode 2 : Activer les deux modes

Vous pouvez activer les deux pour voir d'abord les tests unitaires, puis les tests visuels :
```cpp
#define RUN_UNIT_TESTS true
#define RUN_VISUAL_TESTS true  // Sera exécuté après les tests unitaires
```

## 📊 Exemple de Sortie

```
═══════════════════════════════════════════════════════════
TEST 4: FULL PATH VISUALIZATION
(Interpolation + Kinematics Verification)
═══════════════════════════════════════════════════════════

Full path test:
Start: (150.00, 100.00) mm
End: (200.00, 200.00) mm

Start reachable: YES ✅
End reachable: YES ✅

Start and end angles:
Start: θ1=45.00°, θ2=30.00°
End: θ1=60.00°, θ2=45.00°

Interpolated path (25 points):
─────────────────────────────────────────────────────────────
Point# | X (mm)  | Y (mm)  | θ1 (°)  | θ2 (°)  | Error (mm) | Status
─────────────────────────────────────────────────────────────
    0 |  150.00 |  100.00 |   45.00 |   30.00 |     0.0000 | ✅
    5 |  160.00 |  120.00 |   48.50 |   35.20 |     0.0023 | ✅
   10 |  170.00 |  140.00 |   52.00 |   40.40 |     0.0018 | ✅
   15 |  180.00 |  160.00 |   55.50 |   42.60 |     0.0031 | ✅
   20 |  190.00 |  180.00 |   58.00 |   43.80 |     0.0027 | ✅
   24 |  200.00 |  200.00 |   60.00 |   45.00 |     0.0000 | ✅
─────────────────────────────────────────────────────────────

Summary:
  Total points: 25
  Passed: 25 ✅
  Failed: 0 ❌
  Max error: 0.0031 mm

✅ All interpolation points verified successfully!
```

## 🔍 Interprétation des Résultats

### ✅ Points Passés
- L'erreur est < 0.1 mm
- Les angles calculés permettent d'atteindre la position cible avec précision

### ❌ Points Échoués
- L'erreur est > 0.1 mm
- Possible problème dans :
  - Le calcul de cinématique inverse
  - La précision des calculs
  - Les limites de l'espace de travail

### Erreur de Vérification
L'erreur montre la différence entre :
- La position cible (point interpolé)
- La position calculée en utilisant les angles (round-trip)

**Formule :**
```
Erreur = distance(position_cible, position_verification)
```

## 🛠️ Personnaliser les Tests

Vous pouvez modifier les points de test dans `src/test/TestVisual.cpp` :

### Changer les points de départ/arrivée
Dans `testFullPathVisual()`, modifiez :
```cpp
Point2D start(150.0f, 100.0f);  // Votre point de départ
Point2D end(200.0f, 200.0f);    // Votre point d'arrivée
```

### Changer la vitesse d'interpolation
```cpp
Planner planner(50.0f, 200.0f);  // Vitesse (mm/s), Accélération (mm/s²)
```

### Afficher plus/moins de points
Dans la boucle d'affichage, modifiez :
```cpp
if (index % 5 == 0 || index == 0 || index == numPoints - 1) {
    // Affiche tous les 5 points
    // Changez 5 en 1 pour tout afficher, ou 10 pour moins de détails
}
```

## 📝 Notes Importantes

1. **Les tests visuels ne nécessitent pas de matériel** - ils fonctionnent sans moteurs connectés
2. **Les valeurs sont en millimètres** - vérifiez vos longueurs de bras dans `Config.h`
3. **Les angles sont en degrés** - 0° = droite, 90° = haut, 180° = gauche
4. **L'erreur acceptable** - généralement < 0.1 mm est excellent pour un robot SCARA

## 🐛 Dépannage

### Si tous les tests échouent :
- Vérifiez les longueurs de bras dans `Config.h` (ARM_LENGTH_1, ARM_LENGTH_2)
- Vérifiez que les points sont dans l'espace de travail

### Si l'erreur est élevée :
- Vérifiez la précision des calculs de cinématique
- Vérifiez les arrondis dans les calculs

### Si le Serial Monitor ne montre rien :
- Vérifiez que `RUN_VISUAL_TESTS` est bien à `true`
- Vérifiez la vitesse du port série (115200 baud)
- Attendez quelques secondes après le reset

## 🎓 Comprendre les Résultats

Le **Test 4 (Full Path)** est le plus important car il vérifie :
1. ✅ Que l'interpolation génère des points réguliers
2. ✅ Que chaque point peut être atteint (cinématique inverse fonctionne)
3. ✅ Que les angles calculés permettent vraiment d'atteindre la position (round-trip)

Si ce test passe, votre système d'interpolation et de cinématique fonctionne correctement ! 🎉

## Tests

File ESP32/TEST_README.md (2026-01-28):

# Guide des Tests Unitaires

Ce document explique comment exécuter les tests unitaires pour vérifier le bon fonctionnement du système SCARA Robot.

## Structure des Tests

Les tests sont organisés dans le répertoire `src/test/` :

```
src/test/
├── TestRunner.h/.cpp       # Framework de test
├── RunTests.h/.cpp         # Point d'entrée principal
├── TestTypes.h/.cpp       # Tests des structures de données
├── TestKinematics.h/.cpp  # Tests de cinématique
├── TestPlanner.h/.cpp     # Tests du planificateur
└── TestStepperMotor.h/.cpp # Tests des moteurs (simulation)
```

## Comment Exécuter les Tests

### Méthode 1 : Via Configuration (Recommandé)

1. Ouvrez `src/Config.h`
2. Changez la ligne :
   ```cpp
   #define RUN_UNIT_TESTS false
   ```
   en :
   ```cpp
   #define RUN_UNIT_TESTS true
   ```
3. Compilez et téléversez le code sur l'ESP32
4. Ouvrez le moniteur série (115200 baud)
5. Les tests s'exécuteront automatiquement au démarrage

### Méthode 2 : Via Serial Monitor

Si vous préférez garder `RUN_UNIT_TESTS false`, vous pouvez ajouter une commande série pour déclencher les tests.

## Tests Disponibles

### 1. Tests Types (`TestTypes`)
- ✅ Constructeurs par défaut
- ✅ Constructeurs paramétrés
- ✅ Opérateurs d'égalité
- ✅ Initialisation des structures

### 2. Tests Kinematics (`TestKinematics`)
- ✅ Cinématique directe (angles → position)
  - Angles à 0°
  - Angles à 90°
  - Angles à 180°
- ✅ Cinématique inverse (position → angles)
  - Position droite (0°)
  - Position verticale (90°)
  - Chemin circulaire
- ✅ Vérification de l'espace de travail
  - Points accessibles
  - Points hors portée
  - Cas limites
- ✅ Tests aller-retour (round-trip)
  - Simple
  - Multiples angles

### 3. Tests Planner (`TestPlanner`)
- ✅ Planification de trajectoire simple
- ✅ Distances courtes et longues
- ✅ Variation de vitesse
- ✅ Intervalle d'interpolation
- ✅ Cas limites (même point, lignes verticales/horizontales)
- ✅ Calcul de distance

### 4. Tests StepperMotor (`TestStepperMotor`)
- ✅ Initialisation
- ✅ Enable/Disable
- ✅ Conversion angle ↔ steps
- ✅ Mouvement vers angle
- ✅ État de mouvement
- ✅ Configuration de vitesse

## Interprétation des Résultats

### Format de Sortie

```
╔══════════════════════════════════════════════════════════╗
║         ESP32 SCARA ROBOT - UNIT TESTS                   ║
╚══════════════════════════════════════════════════════════╝

========================================
TEST SUITE: TYPES
========================================
  [TEST] Point2D: Default constructor... PASS
  [TEST] Point2D: Parameterized constructor... PASS
  ...

========================================
TEST RESULTS
========================================
Total:  25
Passed: 25
Failed: 0

✅ ALL TESTS PASSED!
========================================
```

### Codes de Statut

- **PASS** : Le test a réussi ✅
- **FAIL** : Le test a échoué ❌
  - Les détails de l'échec sont affichés avec les valeurs attendues vs réelles

## Ajouter de Nouveaux Tests

### Exemple : Ajouter un test dans TestKinematics

1. Ajoutez la déclaration dans `TestKinematics.h` :
   ```cpp
   static bool testMonNouveauTest();
   ```

2. Implémentez le test dans `TestKinematics.cpp` :
   ```cpp
   bool TestKinematics::testMonNouveauTest() {
       Kinematics kin(150.0f, 150.0f);
       TestRunner runner(false);
       
       // Votre logique de test ici
       return runner.assertTrue(condition);
   }
   ```

3. Ajoutez l'appel dans `runAllTests()` :
   ```cpp
   runner.runTest("Mon nouveau test", testMonNouveauTest);
   ```

## Débogage des Tests

### Activer les Messages de Debug

Dans `Config.h`, activez les flags de debug :
```cpp
#define DEBUG_KINEMATICS true
#define DEBUG_PLANNER true
#define DEBUG_MOTOR true
```

### Vérifier les Assertions

Si un test échoue, le framework affiche :
- La valeur attendue
- La valeur obtenue
- La différence (pour les nombres flottants)
- Un message optionnel

## Tests avec Matériel Réel

⚠️ **Note importante** : Les tests actuels sont conçus pour fonctionner sans matériel réel. Pour tester avec les moteurs connectés :

1. Connectez les moteurs selon `Config.h`
2. Modifiez les tests pour inclure des délais réels
3. Ajoutez des vérifications de position réelle (encodeurs, etc.)

## Prochaines Étapes

Après avoir exécuté les tests unitaires :

1. ✅ Vérifiez que tous les tests passent
2. 🔧 Corrigez les échecs éventuels
3. 🧪 Testez l'intégration complète (sans mode test)
4. 🤖 Testez avec le matériel réel

## Support

Si vous rencontrez des problèmes :
- Vérifiez que `RUN_UNIT_TESTS` est bien défini
- Vérifiez la vitesse du port série (115200 baud)
- Consultez les messages d'erreur dans le Serial Monitor

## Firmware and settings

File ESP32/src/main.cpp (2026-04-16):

/**
 * @file main.cpp
 * @brief ESP32 SCARA Robot Controller - G-Code Style State Machine
 *
 * Professional G-code controller (GRBL/Marlin style) using FreeRTOS
 * dual-core architecture:
 *
 *   Core 0: Web Server (HTTP, WebSocket, ACK)
 *   Core 1: G-Code State Machine (100Hz loop)
 *
 * Motion Pipeline:
 *   WebSocket -> commandQueue(30) -> [STATE MACHINE on Core 1]
 *                                     ↓
 *                                     IDLE / EXECUTING / TOOL_ACTUATING / DELAYING
 *                                     ↓
 *                                     syncWriteAngles -> Dynamixel motors
 *
 * Commands are processed SEQUENTIALLY. Each command must complete (motion
 * finished, tool actuated, delay elapsed) before the next one starts.
 * This guarantees TOOL_DOWN completes before the next MOVE_TO begins.
 */

#include <Arduino.h>
#include <WiFi.h>
#include <Preferences.h>
#include <freertos/FreeRTOS.h>
#include <freertos/queue.h>
#include <freertos/task.h>
#include "Config.h"
#include "core/Kinematics.h"
#include "core/Planner.h"
#include "core/Types.h"

#include "hardware/DynamixelController.h"
#include "web/WebServer.h"
#include "hardware/SG90.h"
#include <queue>  // For std::queue in state machine

// Test mode includes
#if RUN_UNIT_TESTS || RUN_VISUAL_TESTS || RUN_INTERACTIVE_TEST || RUN_INTERACTIVE_TEST2 || \
    RUN_DYNAMIXEL_COMM_TEST || RUN_EFFECTOR_TEST
#include "test/RunTests.h"
#endif

// ============================================================================
// Global Objects
// ============================================================================
Kinematics kinematics(ARM_LENGTH_1, ARM_LENGTH_2);
Planner planner(DEFAULT_SPEED, ACCELERATION);
RobotState robotState;

// Motor instance
DynamixelController* dxlCtrl = nullptr;

WebServer webServer;
SG90 toolServo;  // Global servo instance

// ============================================================================
// FreeRTOS Queues
// ============================================================================
QueueHandle_t commandQueue;  // Commands from web interface (30 slots)

// ============================================================================
// Stop flag (set by STOP command, checked by state machine)
// ============================================================================
volatile bool stopRequested = false;

// ============================================================================
// FreeRTOS Task Handles
// ============================================================================
TaskHandle_t taskWebHandlerHandle = nullptr;
TaskHandle_t taskStateMachineHandle = nullptr;

// ============================================================================
// Task Function Prototypes
// ============================================================================
void taskWebHandler(void* parameter);
void taskStateMachine(void* parameter);

// ============================================================================
// Setup Function
// ============================================================================
void setup() {
    Serial.begin(SERIAL_BAUD_RATE);
    Serial2.begin(SERIAL_OPENRB_BAUD_RATE, SERIAL_8N1, RXD2, TXD2);
    delay(1000);

#if RUN_INTERACTIVE_TEST
    runInteractiveTest();
    return;
#endif

#if RUN_INTERACTIVE_TEST2
    runInteractiveTest2();
    return;
#endif

#if RUN_DYNAMIXEL_COMM_TEST
    runDynamixelCommTest();
    return;
#endif

#if RUN_EFFECTOR_TEST
    runEffectorTest();
    return;
#endif

#if RUN_VISUAL_TESTS
    runVisualTestsOnly();
    return;
#endif

#if RUN_UNIT_TESTS
    runAllUnitTests();
    return;
#endif

    Serial.println("\n\n============================================================");
    Serial.println("ESP32 SCARA Robot Controller — G-Code State Machine");
    Serial.println("  Sequential Command Processing (GRBL/Marlin style)");
    Serial.println("============================================================");
    Serial.printf("  Arms:      L1=%.0fmm  L2=%.0fmm\n", ARM_LENGTH_1, ARM_LENGTH_2);
    Serial.printf("  Workspace: r=[%.0f, %.0f]mm\n", WORKSPACE_R_MIN, WORKSPACE_R_MAX);
    Serial.printf("  Theta1:    [%.0f, %.0f] deg\n", THETA1_MIN, THETA1_MAX);
    Serial.printf("  Theta2:    [%.0f, %.0f] deg\n", THETA2_MIN, THETA2_MAX);
    Serial.printf("  Home:      (%.0f, %.0f)\n", HOME_X, HOME_Y);
    Serial.println("============================================================\n");

    // Initialize hardware
    Serial.println("Initializing hardware...");
    dxlCtrl = new DynamixelController(Serial2);
    dxlCtrl->init();

    // Load home offsets from NVS (flash persistence)
    Preferences prefs;
    prefs.begin("plasmarm", true);  // read-only
    float savedOff1 = prefs.getFloat("off1", -1.0f);
    float savedOff2 = prefs.getFloat("off2", -1.0f);
    prefs.end();
    if (savedOff1 >= 0.0f && savedOff2 >= 0.0f) {
        dxlCtrl->setOffsets(savedOff1, savedOff2);
        Serial.printf("Home offsets loaded from NVS: (%.2f, %.2f)\n", savedOff1, savedOff2);
    } else {
        Serial.println("No saved home offsets, using defaults");
    }

    dxlCtrl->setTorque(true);
    Serial.println("Motors initialized");

    // Tool/Z GPIO setup
    toolServo = SG90(TOOL_SERVO_PIN, TOOL_SWITCH_PIN, 0);
    Serial.println("Tool servo initialized");

    // Create FreeRTOS queue
    commandQueue = xQueueCreate(COMMAND_QUEUE_SIZE, sizeof(Command));
    Serial.printf("commandQueue: %d slots (%d bytes each)\n", COMMAND_QUEUE_SIZE, sizeof(Command));

    // Connect to WiFi or create AP
    if (WIFI_AP_MODE) {
        Serial.print("Creating Access Point: ");
        Serial.println(WIFI_AP_SSID);
        WiFi.softAP(WIFI_AP_SSID, WIFI_AP_PASSWORD);
        Serial.println("\nAccess Point started!");
        Serial.print("IP address: ");
        Serial.println(WiFi.softAPIP());
        webServer.init(commandQueue);
        webServer.begin();
    } else {
        Serial.print("Connecting to WiFi: ");
        Serial.println(WIFI_STA_SSID);
        WiFi.mode(WIFI_STA);
        WiFi.begin(WIFI_STA_SSID, WIFI_STA_PASSWORD);
        int retry = 0;
        while (WiFi.status() != WL_CONNECTED && retry < 20) {
            delay(500);
            Serial.print(".");
            retry++;
        }
        if (WiFi.status() == WL_CONNECTED) {
            Serial.println("\nWiFi connected!");
            Serial.print("IP address: ");
            Serial.println(WiFi.localIP());
            webServer.init(commandQueue);
            webServer.begin();
        } else {
            Serial.println("\nWiFi connection failed!");
        }
    }

    // Create FreeRTOS tasks

    // Task 1: Web Handler (Core 0, Low Priority)
    xTaskCreatePinnedToCore(taskWebHandler, "WebHandler", TASK_WEB_HANDLER_STACK_SIZE, nullptr,
                            TASK_WEB_HANDLER_PRIORITY, &taskWebHandlerHandle,
                            0  // Core 0
    );

    // Task 2: G-Code State Machine (Core 1, Medium Priority)
    xTaskCreatePinnedToCore(taskStateMachine, "GCodeSM", TASK_PLANNER_STACK_SIZE * 2, nullptr,
                            TASK_PLANNER_PRIORITY, &taskStateMachineHandle,
                            1  // Core 1
    );

    Serial.println("\nFreeRTOS tasks created:");
    Serial.println("  - WebHandler (Core 0, Priority 1)");
    Serial.println("  - GCodeSM   (Core 1, Priority 2) — 100Hz state machine");
    Serial.printf("\nInitial position: (%.1f, %.1f) z=%.1f tool=%s\n", robotState.currentPosition.x,
                  robotState.currentPosition.y, robotState.toolZ,
                  robotState.toolActive ? "ON" : "OFF");
    Serial.println("\nSystem ready!\n");
}

// ============================================================================
// Loop Function (not used — FreeRTOS tasks handle everything)
// ============================================================================
void loop() {
    webServer.cleanup();
    delay(1000);
}

// ============================================================================
// Task A: Web Handler (Core 0)
// ============================================================================
void taskWebHandler(void* parameter) {
    Serial.println("Task WebHandler started on Core 0");

    unsigned long lastStatusBroadcast = 0;
    const unsigned long STATUS_BROADCAST_INTERVAL_MS = 500;

    while (true) {
        webServer.cleanup();

        unsigned long now = millis();
        if (now - lastStatusBroadcast >= STATUS_BROADCAST_INTERVAL_MS) {
            lastStatusBroadcast = now;
            webServer.broadcastStatus(robotState);
        }

        vTaskDelay(pdMS_TO_TICKS(50));
    }
}

// ============================================================================
// Task B: G-Code State Machine (Core 1, 100Hz)
// ============================================================================
void taskStateMachine(void* parameter) {
    Serial.println("Task GCodeSM started on Core 1 (100Hz)");

    // --- Timing setup ---
    const TickType_t loopDelay = pdMS_TO_TICKS(1000 / MOTION_CONTROL_FREQUENCY);
    TickType_t lastWakeTime = xTaskGetTickCount();

    // --- State machine ---
    PlannerState state = PlannerState::IDLE;

    // --- Delay tracking (like TestInteractive2) ---
    uint32_t delayStartTime = 0;
    uint32_t delayDuration = 0;

    // --- Tool actuation tracking (non-blocking) ---
    bool toolMovingDown = false;
    bool toolMovingUp = false;
    float toolTargetAngle = 0.0f;
    uint32_t toolActuateStartTime = 0;

    // --- Motion point buffer (internal, not a FreeRTOS queue) ---
    std::queue<TargetState> pointBuffer;
    std::queue<TargetState> transitBuffer; // For JOINT mode safe transit paths
    ArmConfig currentConfig = ArmConfig::RIGHT_ELBOW;

    // --- Config switch tracking ---
    ArmConfig targetConfig = currentConfig;  // Config to switch to
    bool configSwitchPending = false;        // Trigger config switch
    TargetState switchTarget;                // Store target for path regeneration
    bool restoreToolAfterSwitch = false;

    // --- Current position tracking (XY only — tool state lives in servo/robotState) ---
    TargetState currentState(robotState.currentPosition.x, robotState.currentPosition.y);

    // --- Serial logging ---
    static unsigned long lastStatusLog = 0;
    const unsigned long STATUS_LOG_INTERVAL_MS = 500;

    while (true) {
        // ====================================================================
        // 1. CHECK STOP REQUEST (from any task via volatile flag)
        // ====================================================================
        if (stopRequested) {
            Serial.println("SM: STOP REQUESTED");
            stopRequested = false;
            
            // Move tool up
            toolTargetAngle = 175.0f;  // Retracted position
            toolMovingDown = false;
            toolMovingUp = true;
            toolActuateStartTime = millis();
            state = PlannerState::TOOL_ACTUATING;
            robotState.plannerState = PlannerState::TOOL_ACTUATING;

            // Clear pending commands
            xQueueReset(commandQueue);

            // Drain internal buffers
            while (!pointBuffer.empty())
                pointBuffer.pop();
            while (!transitBuffer.empty())
                transitBuffer.pop();

            // Safety: disable tool actuating logic
            toolMovingDown = false;
            configSwitchPending = false;
            
            if (dxlCtrl) {
                dxlCtrl->update();
                dxlCtrl->stop();  // COMMAND MOTORS TO STOP IMMEDIATELY
            }

            Serial.println("SM: STOP! Cleared all queues, tool OFF, state -> IDLE");
        }

        // ====================================================================
        // 2. STATE: DELAYING — check if delay has elapsed
        // ====================================================================
        if (state == PlannerState::DELAYING) {
            uint32_t elapsed = millis() - delayStartTime;
            if (elapsed >= delayDuration) {
                Serial.printf("SM: DELAY complete (%lu ms)\n", (unsigned long)delayDuration);
                if (!transitBuffer.empty() || !pointBuffer.empty()) {
                    state = PlannerState::EXECUTING;
                    robotState.plannerState = PlannerState::EXECUTING;
                } else {
                    state = PlannerState::IDLE;
                    robotState.plannerState = PlannerState::IDLE;
                }
            }
        }

        // ====================================================================
        // 3. STATE: EXECUTING — send interpolated points at 100Hz
        // ====================================================================
        if (state == PlannerState::EXECUTING) {
            std::queue<TargetState>* activeBuffer = nullptr;
            if (!transitBuffer.empty()) activeBuffer = &transitBuffer;
            else if (!pointBuffer.empty()) activeBuffer = &pointBuffer;
            
            if (activeBuffer != nullptr) {
                TargetState target = activeBuffer->front();

                if (target.mode == MoveMode::JOINT) {
                    // Bypass IK, move dynamically in joint space
                    activeBuffer->pop();
                    if (dxlCtrl) dxlCtrl->syncWriteAngles(target.x, target.y);
                    
                    JointAngles targetAngles(target.x, target.y);
                    robotState.currentAngles = targetAngles;
                    
                    // Maintain Cartesian position correctly via Forward Kinematics for UI
                    Point2D fkXY;
                    kinematics.forward(targetAngles, fkXY);
                    robotState.currentPosition = fkXY;
                    robotState.isMoving = true;
                    currentState = target; 
                } else if (target.mode == MoveMode::DELAY_MS) {
                    activeBuffer->pop();
                    delayDuration = target.x;
                    delayStartTime = millis();
                    state = PlannerState::DELAYING;
                    robotState.plannerState = PlannerState::DELAYING;
                } else if (target.mode == MoveMode::TOOL_UP_ASYNC) {
                    activeBuffer->pop();
                    Serial.println("SM: Async TOOL_UP from transit buffer");
                    toolTargetAngle = 175.0f;
                    toolMovingDown = false;
                    toolMovingUp = true;
                    toolActuateStartTime = millis();
                    state = PlannerState::TOOL_ACTUATING;
                    robotState.plannerState = PlannerState::TOOL_ACTUATING;
                    robotState.isMoving = true;
                } else if (target.mode == MoveMode::TOOL_DOWN_ASYNC) {
                    activeBuffer->pop();
                    Serial.println("SM: Async TOOL_DOWN from transit buffer");
                    toolMovingDown = true;
                    toolMovingUp = false;
                    toolActuateStartTime = millis();
                    state = PlannerState::TOOL_ACTUATING;
                    robotState.plannerState = PlannerState::TOOL_ACTUATING;
                    robotState.isMoving = true;
                } else {
                    // Mode is CARTESIAN
                    Point2D targetXY = target.toPoint2D();
                    JointAngles targetAngles;
                    ArmConfig usedConfig;

                    //bool ikSuccess = kinematics.inverse(targetXY, targetAngles, currentConfig, usedConfig);
                    bool ikSuccess = kinematics.inverse(targetXY, targetAngles, currentConfig);
                    if (!ikSuccess) {
                        Serial.printf("SM: IK failed for (%.2f, %.2f)\n", targetXY.x, targetXY.y);
                        activeBuffer->pop();
                    } else if (usedConfig != currentConfig) {
                        Serial.printf("SM: Config switch needed: %s -> %s at (%.1f, %.1f)\n",
                                      currentConfig == ArmConfig::RIGHT_ELBOW ? "RIGHT" : "LEFT",
                                      usedConfig == ArmConfig::RIGHT_ELBOW ? "RIGHT" : "LEFT",
                                      targetXY.x, targetXY.y);
                        /*
                        targetConfig = usedConfig;
                        configSwitchPending = true;
                        // Check actual servo position — robotState.toolActive may have
                        // been overwritten to false by interpolated MOVE_TO points
                        restoreToolAfterSwitch = (toolServo.getAngle() < 150);

                        state = PlannerState::SWITCH_RAISE_TOOL;
                        robotState.plannerState = PlannerState::SWITCH_RAISE_TOOL;
                        robotState.isMoving = true;
                        Serial.printf("SM:   servoAngle=%d, restoreTool=%s\n",
                                      toolServo.getAngle(),
                                      restoreToolAfterSwitch ? "YES" : "NO");
                        // Note: We deliberately DO NOT pop the buffer here. The point stays at the front for later execution.
                    */
                    }else {
                        activeBuffer->pop();
                        if (dxlCtrl) {
                            dxlCtrl->syncWriteAngles(targetAngles.theta1, targetAngles.theta2);
                        }
                        robotState.currentAngles = targetAngles;
                        robotState.currentPosition = targetXY;
                        robotState.isMoving = true;
                        currentState = TargetState(targetXY.x, targetXY.y);
                    }
                }
            } else {
                // No more points — check if motors have settled
                if (dxlCtrl)
                    dxlCtrl->update();
                bool motorsMoving = dxlCtrl ? dxlCtrl->isMoving() : false;
                robotState.isMoving = motorsMoving;

                if (!motorsMoving) {
                    Serial.println("SM: MOVE complete, motors idle");
                    state = PlannerState::IDLE;
                    robotState.plannerState = PlannerState::IDLE;
                    robotState.isMoving = false;
                }
            }
        }

        // ====================================================================
        // 4. STATE: TOOL_ACTUATING — non-blocking servo motion
        // ====================================================================
        if (state == PlannerState::TOOL_ACTUATING) {
            Serial.printf("SM: TOOL_ACTUATING loop (down=%d, up=%d, angle=%f, switch=%d)\n",
                          toolMovingDown, toolMovingUp, toolServo.getAngle(),
                          digitalRead(TOOL_SWITCH_PIN));
            bool done = false;
            if (toolMovingDown && !done) {
                done = toolServo.stepDown(TOOL_STEP_DEG);
                uint32_t elapsed = millis() - toolActuateStartTime;
                if (elapsed > TOOL_ACTUATE_TIMEOUT_MS) {
                    Serial.println("SM: TOOL_DOWN timeout!");
                    done = true;
                }
            } else if (toolMovingUp && !done) {
                done = toolServo.stepUp(TOOL_STEP_DEG, toolTargetAngle);
            }

            if (done) {
                Serial.println("SM: TOOL actuation complete");
                bool wasDown = toolMovingDown;
                bool wasUp = toolMovingUp;
                toolMovingDown = false;
                toolMovingUp = false;
                if (wasDown) {
                    robotState.toolZ = 5.0f;
                    robotState.toolActive = true;
                } else if (wasUp) {
                    robotState.toolZ = 0.0f;
                    robotState.toolActive = false;
                }
                
                if (!transitBuffer.empty() || !pointBuffer.empty()) {
                    state = PlannerState::EXECUTING;
                    robotState.plannerState = PlannerState::EXECUTING;
                } else {
                    state = PlannerState::IDLE;
                    robotState.plannerState = PlannerState::IDLE;
                    robotState.isMoving = false;
                }
            }
        }

        // ====================================================================
        // 5. STATE: SWITCH_RAISE_TOOL — raise tool non-blockingly before switch
        // ====================================================================
        if (state == PlannerState::SWITCH_RAISE_TOOL) {
            if (restoreToolAfterSwitch) {
                // Initialize servo upward motion if not already moving
                if (!toolMovingUp) {
                    Serial.println("SM:   Tool is DOWN - raising before config switch");
                    toolTargetAngle = 175.0f;
                    toolMovingDown = false;
                    toolMovingUp = true;
                    toolActuateStartTime = millis();
                }
                
                bool done = toolServo.stepUp(TOOL_STEP_DEG, toolTargetAngle);
                if (done) {
                    toolMovingUp = false;
                    Serial.println("SM:   Tool raised");
                    robotState.toolZ = 0.0f;
                    robotState.toolActive = false;
                    
                    state = PlannerState::SWITCHING_CONFIG;
                    robotState.plannerState = PlannerState::SWITCHING_CONFIG;
                }
            } else {
                // Tool already up, proceed immediately
                state = PlannerState::SWITCHING_CONFIG;
                robotState.plannerState = PlannerState::SWITCHING_CONFIG;
            }
        }
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

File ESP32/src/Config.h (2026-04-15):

#ifndef CONFIG_H
#define CONFIG_H

#include <Arduino.h>

// ============================================================================
// WiFi Configuration
// ============================================================================
// Set to true to create an Access Point, false to connect to an existing WiFi
#define WIFI_AP_MODE true

// AP Mode Settings (When WIFI_AP_MODE is true)
#define WIFI_AP_SSID "PlasmArm_ESP32"
#define WIFI_AP_PASSWORD "12345678"  // Must be at least 8 characters

// Station Mode Settings (When WIFI_AP_MODE is false)
#define WIFI_STA_SSID "nom du mot du wifi"
#define WIFI_STA_PASSWORD "mot de passe"

#define WIFI_TIMEOUT_MS 10000

// ============================================================================
// Robot Physical Parameters
// ============================================================================
// Arm lengths in millimeters
#define ARM_LENGTH_1 220.05f  // Length of first link (base to elbow)
#define ARM_LENGTH_2 217.65f  // Length of second link (elbow to end effector)

// Joint angle limits (degrees, measured from +X axis, CCW positive)
#define THETA1_MIN 0.0f     // Slightly past +X axis (clockwise)
#define THETA1_MAX 180.0f   // Slightly past -X axis (counter-clockwise)
#define THETA2_MIN -150.0f  // Fully extended
#define THETA2_MAX 150.0f   // Practical folding limit

// Workspace limits (SCARA half-circle workspace)
// The robot sits at the origin (0,0) and can reach a half-annulus
// in the upper half-plane (y > 0).
//
//               (0, R_MAX)            Outer boundary: r = L1+L2 = R_MAX
//                  |                Inner boundary: r =
//                 / \               Half-plane:     y > 0
//    (-R_MAX,0)----+---+----(R_MAX,0)   Theta1 range:   0° to 180°
//               (BASE)
//
#define WORKSPACE_R_MAX (ARM_LENGTH_1 + ARM_LENGTH_2)  // max reach
#define WORKSPACE_R_MIN ARM_LENGTH_1 - std::cos(THETA2_MAX) * ARM_LENGTH_2  // Minimum reach - prevents arm folding on itself

// Home position: arm fully extended upward (+Y direction)
#define HOME_X WORKSPACE_R_MAX
#define HOME_Y 0.0f
#define HOME_THETA1 90.0f  // Pointing up
#define HOME_THETA2 0.0f   // Fully extended

// ============================================================================
// Motor Configuration
// ============================================================================
// Motor 1 (Base Joint) - Stepper Motor Pins
#define MOTOR1_STEP_PIN 19
#define MOTOR1_DIR_PIN 18
#define MOTOR1_ENABLE_PIN 27

// Motor 2 (Elbow Joint) - Stepper Motor Pins
// WARNING: GPIO12 is a STRAPPING PIN! It controls boot flash voltage.
// If motor driver holds GPIO12 HIGH during boot, ESP32 won't boot.
// Ensure motor driver has pulldown or is LOW during power-on.
#define MOTOR2_STEP_PIN 14
#define MOTOR2_DIR_PIN 12
#define MOTOR2_ENABLE_PIN 13

// Stepper motor parameters
#define STEPS_PER_REVOLUTION 200  // 1.8° per step
#define MICROSTEPS 16             // Microstepping factor
#define STEPS_PER_DEGREE ((STEPS_PER_REVOLUTION * MICROSTEPS) / 360.0f)

// Servo motor parameters (if using servos instead)
#define SERVO1_PIN 20
#define SERVO2_PIN 21
#define SERVO_MIN_PULSE 500   // microseconds
#define SERVO_MAX_PULSE 2500  // microseconds

// Tool output (relay, plasma torch trigger, etc.)
#define TOOL_SERVO_PIN 26   // pin pour donner les positions du servo
#define TOOL_SWITCH_PIN 32  // pin pour lire l'état du switch de pression

// Tool actuation parameters
#define TOOL_STEP_DEG 0.4f            // degrees per step (non-blocking speed control)
#define TOOL_ACTUATE_TIMEOUT_MS 5000  // max time for down motion before timeout

// Serial communication with Dynamixels
#define RXD2 16
#define TXD2 17

// ============================================================================
// Motion Control Parameters
// ============================================================================
#define DEFAULT_SPEED 50.0f  // mm/s
#define MAX_SPEED 100.0f     // mm/s
#define ACCELERATION 200.0f  // mm/s²
#define JERK_LIMIT 500.0f    // mm/s³

// Interpolation parameters
#define INTERPOLATION_INTERVAL_MS 10  // Time between interpolated points
#define MIN_SEGMENT_LENGTH 0.1f       // Minimum segment length in mm

// ============================================================================
// FreeRTOS Task Configuration
// ============================================================================
// Stack sizes (in words, 1 word = 4 bytes on ESP32)
#define TASK_WEB_HANDLER_STACK_SIZE 8192     // 32 KB
#define TASK_PLANNER_STACK_SIZE 4096         // 16 KB
#define TASK_MOTION_CONTROL_STACK_SIZE 4096  // 16 KB

// Task priorities (higher number = higher priority)
#define TASK_WEB_HANDLER_PRIORITY 1
#define TASK_PLANNER_PRIORITY 2
#define TASK_MOTION_CONTROL_PRIORITY 3

// Queue sizes
#define COMMAND_QUEUE_SIZE 30  // High-level commands from host (tune for streaming)

// Motion control loop frequency (Hz)
#define MOTION_CONTROL_FREQUENCY 100  // 100 Hz = 10ms loop
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

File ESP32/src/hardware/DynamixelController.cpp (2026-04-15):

#include "hardware/DynamixelController.h"
#include <Arduino.h>
#include "../Config.h"

const float DynamixelController::POSITION_TOLERANCE = 1.0f;
const float DynamixelController::DEG_TO_PULSE = 4096.0f / 360.0f;

DynamixelController::DynamixelController(HardwareSerial& serial, int dirPin) 
    : dxl(serial, dirPin), hwSerial(serial) {
}

bool DynamixelController::init() {
    // The hardware serial begin should usually be handled by main before init()
    // but the Dynamixel2Arduino begin gives control to the lib.
    dxl.begin(1000000);
    dxl.setPortProtocolVersion(2.0);

    // Check if motors are there
    bool ping1 = dxl.ping(ID_M1);
    bool ping2 = dxl.ping(ID_M2);
    if (!ping1 || !ping2) {
        Serial.println("Error: Could not ping one or both Dynamixel motors!");
        // return false; // We can continue but it's risky
    }

    // === CONFIGURATION MOTEURS ===
    dxl.torqueOff(ID_M1);
    dxl.setOperatingMode(ID_M1, OP_POSITION);
    // Activation du Time-Based Profile (Valeur 4 dans le registre Drive Mode)
    dxl.writeControlTableItem(ControlTableItem::DRIVE_MODE, ID_M1, 4);
    dxl.torqueOn(ID_M1);

    dxl.torqueOff(ID_M2);
    dxl.setOperatingMode(ID_M2, OP_POSITION);
    // Activation du Time-Based Profile (Valeur 4 dans le registre Drive Mode)
    dxl.writeControlTableItem(ControlTableItem::DRIVE_MODE, ID_M2, 4);
    dxl.torqueOn(ID_M2);

    // === PARAMETRAGE DU TEMPS D'INTERPOLATION ===
    // IMPORTANT : Ce temps doit correspondre à l'intervalle d'envoi du ESP32 !
    uint32_t step_time_ms = INTERPOLATION_INTERVAL_MS;
    dxl.writeControlTableItem(ControlTableItem::PROFILE_VELOCITY, ID_M1, step_time_ms);
    dxl.writeControlTableItem(ControlTableItem::PROFILE_VELOCITY, ID_M2, step_time_ms);
    dxl.writeControlTableItem(ControlTableItem::PROFILE_ACCELERATION, ID_M1, 0);
    dxl.writeControlTableItem(ControlTableItem::PROFILE_ACCELERATION, ID_M2, 0);

    // === INITIALISATION SYNCWRITE ===
    sw_infos.packet.p_buf = nullptr;
    sw_infos.packet.is_completed = false;
    sw_infos.addr = SW_START_ADDR;
    sw_infos.addr_length = SW_DATA_LEN;
    sw_infos.p_xels = info_xels;
    sw_infos.xel_count = 0;

    info_xels[0].id = ID_M1;
    info_xels[0].p_data = (uint8_t*)&sw_data_array[0].goal_position;
    sw_infos.xel_count++;

    info_xels[1].id = ID_M2;
    info_xels[1].p_data = (uint8_t*)&sw_data_array[1].goal_position;
    sw_infos.xel_count++;

    sw_infos.is_info_changed = true;
    
    Serial.println("Pret. System SCARA Dynamixel initialise avec Time-Based Profile.");
    return ping1 && ping2;
}

void DynamixelController::syncWriteAngles(float theta1_mech, float theta2_mech) {
    if (homeMode) return; // Prevent movement if in home setup mode

    float angle1_internal = mechToInternal_ID1(theta1_mech);
    float angle2_internal = mechToInternal_ID2(theta2_mech);

    target1_internal = normalize(angle1_internal);
    target2_internal = normalize(angle2_internal);

    // Convert degrees to pulses
    sw_data_array[0].goal_position = (int32_t)(target1_internal * DEG_TO_PULSE);
    sw_data_array[1].goal_position = (int32_t)(target2_internal * DEG_TO_PULSE);

    sw_infos.is_info_changed = true;
    dxl.syncWrite(&sw_infos);

    moving1 = true;
    moving2 = true;
    stallCount1 = 0;
    stallCount2 = 0;
}

float DynamixelController::getAngle(uint8_t id) {
    // Single read — RX flush inside readOneMotor ensures clean data
    float raw = readOneMotor(id);
    if (raw < 0.0f) {
        Serial.printf("Warning: Failed to read motor %d\n", id);
        return 0.0f;
    }
    
    float pos = normalize(raw);
    if (id == ID_M1) {
        return internalToMech_ID1(pos);
    } else if (id == ID_M2) {
        return internalToMech_ID2(pos);
    }
    return 0.0f;
}

void DynamixelController::setTorque(bool enable) {
    if (enable) {
        dxl.torqueOn(ID_M1);
        delay(5);
        dxl.torqueOn(ID_M2);
        delay(5);
    } else {
        dxl.torqueOff(ID_M1);
        delay(5);
        dxl.torqueOff(ID_M2);
        delay(5);
    }
}

void DynamixelController::setHomeMode() {
    Serial.println("=== MODE SET HOME ===");
    setTorque(false);
    homeMode = true;
    moving1 = false;
    moving2 = false;
}
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

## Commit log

2026-01-28 un peu de structure
2026-01-31 try dxf
    [drawing.dxf]
2026-02-03 test dxf
    [drawing.dxf]
2026-02-03 divising esp32 and openRB
    [drawing.dxf]
2026-02-03 divising project
    [arduino_zero.cfg]
2026-02-03 Python
    Ajout du python pour le UI
    [plan.dxf]
2026-02-03 test socket
2026-02-11 Load, close.
    Ajouter bouton pour charger et retirer un dxf de l'affichage
2026-02-11 Print, load
    Print et load centré
    [plan.dxf]
2026-02-17 cooking 4D plus websocket
    [arc299.5.dxf, grosse_spline.dxf, onshape_simple.dxf]
2026-02-17 fixing coordinates
    _
    / \
    | . |
    y
    |___x
    [arc299ypos.dxf]
2026-03-10 Commentaire
    Ajout de commentaire.
2026-03-11 Integration parsing
    L'interface peut créer les commandes (parsing)
    [BMW.dxf]
2026-03-17 robot change arm to be in optimal position in x+ and x-
2026-03-18 arm config switch
    only switch when necessary
    [arduino_zero.cfg]
2026-03-18 logique effecteur
    [arduino_zero.cfg]
2026-03-18 input de la switch
2026-03-20 test web socket
2026-03-26 gros robot plus pcb
2026-03-27 correct reading of angles
    [DynamixelController.cpp, DynamixelController.h, TestDynamixelComm.cpp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]
2026-04-01 Prep Communication
    Préparation communication (fichier séparé)
    Début affichage réel bras robot
    [export_robot.dxf, plan.dxf, rectangle.dxf]
2026-04-01 UI v2
    Début de la V2 de l'interface
    Ajout du logo
    Affichage des bras bien centré
    Ajout des icones
2026-04-08 effector correction and test
    [Config.h, TestEffector.cpp, WebServer.cpp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]
2026-04-08 correct effector in main
    [TestEffector.cpp, main.cpp]
2026-04-09 test switch config main
2026-04-11 switch config test
2026-04-15 ui correction
    [export_robot.dxf]
2026-04-15 Calibration button
    can calibrate from ui
    [rectangle.dxf, udes.dxf]
2026-04-15 fichiers .stl (pieces a imprimer)
    [Base Bas.stl, Base Haut.stl, Bloc anti-friction.stl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]
2026-04-15 Update README with STL printing files link
    Added link to STL printing files in the README.
2026-04-15 servo and e-stop
2026-04-15 Version Fonctionnelle
    [Base Bas.stl, Base Haut.stl, Bloc anti-friction.stl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]
2026-04-15 e-stop fix
    [export_robot.dxf]
2026-04-15 step files folder
    [1-4- ID x 1-2- OD Flanged Ball Bearing.step, 1-4” Bore Set Screw Hub.step, 1-4” x 2” Stainless Steel D-shaft.step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]
2026-04-15 Add STEP Part Files link to README
    Add link to STEP part files in the 3D Printed Parts section.
2026-04-15 trapezoidal profile
    [export_robot.dxf]
2026-04-15 Update README with user interface and component details
    Removed unnecessary details about M3 Heat Inserts and updated the user interface diagram.
2026-04-15 Rename ROBOT COMPLET ASS.png to Mise en plan assemblage complet.png
2026-04-15 Enhance README with mechanical assembly details
    Added detailed mechanical assembly instructions and parts list.
2026-04-15 Add assembly instructions for Base Cover & C-clamp
    Added instructions for Sub-assembly 6: Base Cover & C-clamp.
2026-04-15 Add assembly instructions for end effector and base cover
2026-04-15 Add assembly instruction for C-clamp fitting
    Added instructions for pressing the assembled C-clamp into the base's triangular slot.
2026-04-15 Enhance assembly instructions for Arm 2 and C-clamp
    Added detailed instructions for assembling the second arm and updated the C-clamp reference.
2026-04-16 Rename Mise en plan assemblage complet.png to Complete Robot Assembly Drawing.png
2026-04-16 Rename section from 'Mechanical Parts' to 'BoM & Drawing'
2026-04-16 Fix links in README for BoM and Assembly Instructions
2026-04-16 Fix link formatting in README for BoM section
2026-04-16 Rename Shéma_éléctrique.png to Electrical Wiring Diagram.png
2026-04-16 Change wiring diagram image filename
    Updated the wiring diagram image reference in README.
2026-04-16 Create Assembly Instructions.md
2026-04-16 Document assembly instructions for robot components
    Added detailed assembly instructions for multiple sub-assemblies including motors, arms, and end effector components.
2026-04-16 Remove detailed assembly instructions
    Removed detailed assembly instructions for various sub-assemblies from the README file.
2026-04-16 Fix link to Assembly Instructions in README
2026-04-16 Update assembly instructions with drawing reference
    Added reference to exploded assembly drawing for clarity.
2026-04-16 Add Complete Robot Exploded Assembly Drawing
    Updated assembly instructions to include a new drawing.
2026-04-16 Fix image references in assembly instructions
    Updated image references for assembly instructions.
2026-04-16 Fix image paths and update assembly instruction reference
    Updated image paths and clarified instruction reference.
2026-04-16 Fix typo in BoM and Drawings section header
2026-04-16 Revise component details and wiring diagram
    Updated component specifications and wiring details in the README.
2026-04-16 Nouveau mode calibration
2026-04-16 test for better tool down
    [export_robot.dxf]
2026-04-16 effector fix
    [export_robot.dxf]
2026-04-16 Revise README for electrical and mechanical sections
    Updated the README to reflect changes in hardware and electrical sections, and restructured mechanical assembly information.
2026-04-16 Rename Mechanical Assembly section to Mechanical
    Updated section titles and links for mechanical assembly.
2026-04-16 Update README with new electrical sections
    Added sections for Electrical Components, Bill of Materials, and Wiring Diagram.
2026-04-16 Rename Capture d’écran 2026-04-16 144542.png to Communication Block Diagram.png
2026-04-16 tool correction
    [export_robot.dxf]
2026-04-16 Comment et ui propre
    Logo canadien
    [canadiens_vide.dxf]
